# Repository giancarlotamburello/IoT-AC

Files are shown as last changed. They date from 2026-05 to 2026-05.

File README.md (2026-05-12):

<a href="https://www.ingv.it/" target="_blank" rel="noopener noreferrer">
<picture>
  <source media="(prefers-color-scheme: dark)" srcset="INGV_LOGO_STESO_SX_gray.svg">
  <source media="(prefers-color-scheme: light)" srcset="INGV_LOGO_STESO_SX.svg">
  
</picture>
</a>

<br></br>
<br></br>
<br></br>

# IoT-AC: Internet of Things - Accumulation Chamber Assembly Guide

This project provides the documentation and source files to build a low-cost, IoT-based accumulation chamber (**IoT-AC**) for measuring diffuse CO<sub>2</sub> fluxes.

## Overview

The **IoT-AC** is designed for environmental monitoring, with a focus on soil and volcanic degassing. The system leverages an ESP32 microcontroller to manage gas sensing and internal air homogenization, offering a portable, cost-effective alternative to professional scientific instrumentation. Performance was evaluated across two stages: controlled laboratory characterisation and field deployment within the active crater of Nea Kameni (Santorini). The resulting datasets are available [here](IOT_AC_DATA.md).

## Hardware Components

### Electronics

- **Microcontroller:** [ESP32](https://www.espressif.com/en/products/socs/esp32) (Dual-core, Wi-Fi/Bluetooth enabled).
- **CO2 Sensor:** [Sensirion SCD30](https://sensirion.com/products/catalog/SCD30) – A high-precision NDIR (Non-Dispersive Infrared) module.
- **Fan Motor:** Parallax Inc. bidirectional continuous rotation servomotor (0-50 RPM, 4.6 V).
- **Dupont jumper wires:** 10cm long Dupont jumper wires Female to Female and Male to Female.

### Chamber Specifications

We recommend using a **4-litre aluminium chamber** (e.g., a commercially available rice cooker pot) for the following reasons:

- **Dimensions:** ~20 cm internal diameter, 13 cm height.
- **Material:** Lightweight and durable.
- **Machining:** Easy to drill for mounting components.

> **Note:** Internal air homogenization is critical in closed-chamber systems to maintain a uniform concentration gradient. The integrated fan ensures this without disturbing the soil interface.

<figure>
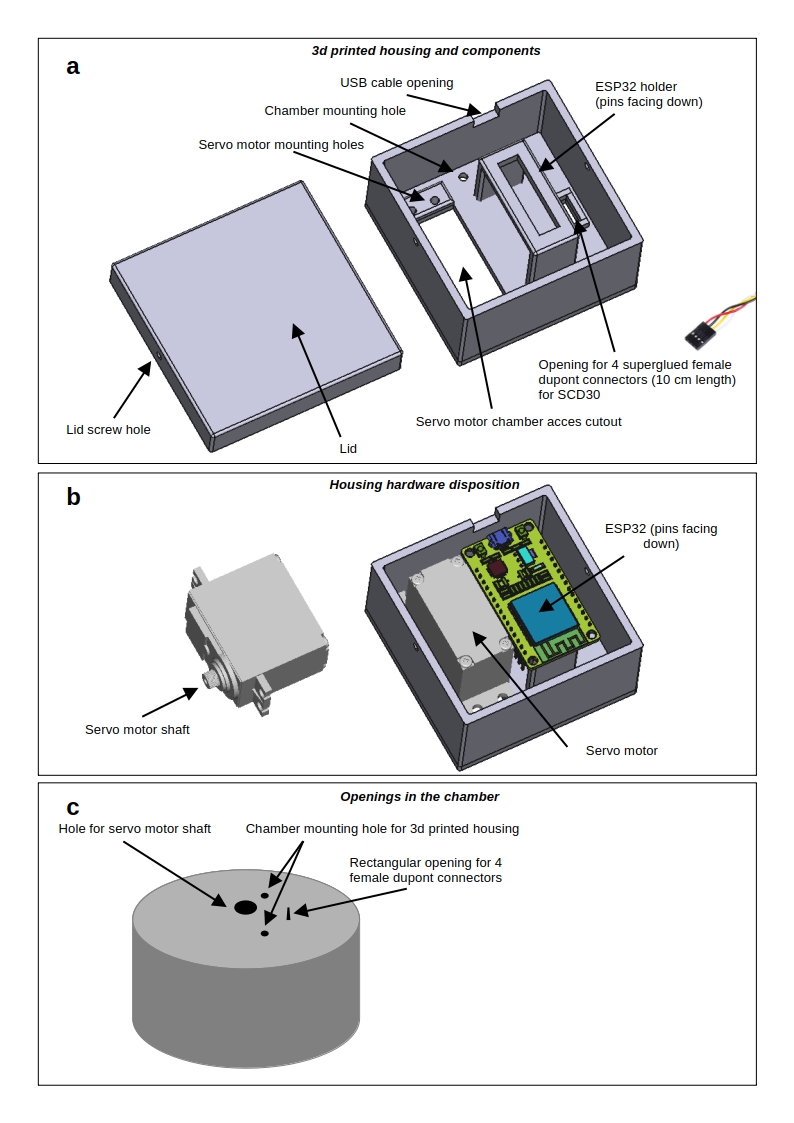
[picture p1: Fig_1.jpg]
  
  <figcaption>Figure 1: Description of the IoT-AC 3D-printed housing parts.</figcaption>
</figure>

---

## Assembly Guide

### 1. Preparation and Drilling

The file `iot_ac_case.3mf` serves as both the electronics enclosure and a **drilling template**. Align the housing on the chamber lid to mark and drill the following four holes (Fig. 1c-2a):

- **Servo Shaft Hole:** For the motor connection to the internal fan (must be at the centre of the chamber).
- **Fixation Holes (x2):** To secure the housing to the chamber body.
- **Sensor Port:** A small rectangular opening for the 4-pin female Dupont connectors used by the SCD30 sensor.

### 2. Mounting and Installation

- **Housing Attachment:** Once the holes are drilled, secure the 3D-printed housing to the chamber using two screws and bolts (Fig. 2b).
- **Servomotor:** Attach the servomotor to the housing using four self-tapping screws (Fig. 2c).
- **Sensor Interface:** Insert the four female Dupont connectors of the SCD30 into the rectangular hole and secure them with superglue (Fig. 2c-e).
  - _Benefit:_ This creates a modular port that allows the sensor to be connected easily inside the chamber and enables fast replacement in the field (Fig. 2d-f).

### 3. Wiring and Final Setup

- **Connections:** Wire the ESP32 to the servomotor and the SCD30 sensor according to the pinout diagram.
- **ESP32 Placement:** Place the ESP32 (pins facing down) onto its support within the housing, fixing it securely with double-sided tape (Fig. 2g).
- **Power:** Connect a USB cable to the ESP32. Ensure the cable length is sufficient for practical field operation.
- **Closure:** Close the housing lid and secure it with two self-tapping screws (Fig. 2h).

<figure>
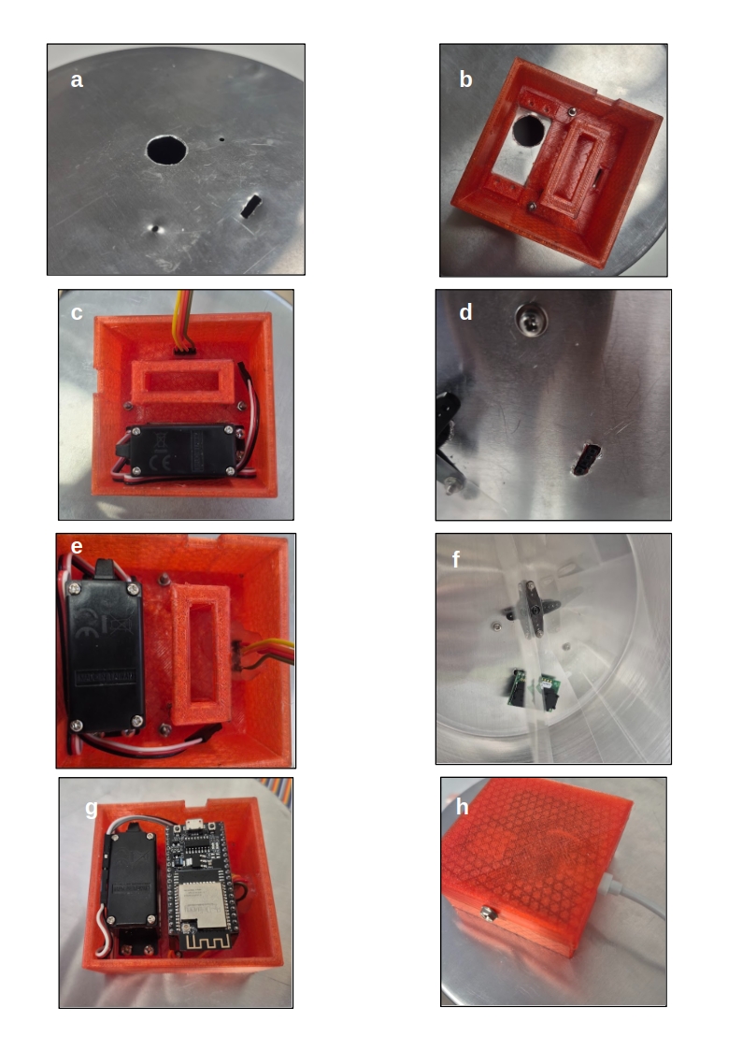
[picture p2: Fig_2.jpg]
  
  <figcaption>Figure 2: Photos of the steps for assembling the IoT-AC.</figcaption>
</figure>

---

## Install firmware and software

To get the system running, you will need to set up both the firmware in the ESP32 microcontroller and install the client application on an Android smartphone. Please refer to the specific documentation for each component:

### 🔌 Firmware

Flash the ESP32 microcontroller.

[**Buld & Flash docs →**](https://github.com/le0o0oo/d-flux/blob/main/firmware/README.md#build--flash)

### 📱 Client Application

Download the desktop/mobile app.

[**Releases →**](https://github.com/le0o0oo/d-flux/releases)

## License

This project is licensed under the **Creative Commons Attribution 4.0 International (CC BY 4.0)**. You are free to share and adapt this material, provided appropriate credit is given.

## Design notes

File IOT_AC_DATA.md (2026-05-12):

<a href="https://www.ingv.it/" target="_blank" rel="noopener noreferrer">
<picture>
  <source media="(prefers-color-scheme: dark)" srcset="https://github.com/giancarlotamburello/IoT-AC/blob/main/INGV_LOGO_STESO_SX_gray.svg">
  <source media="(prefers-color-scheme: light)" srcset="https://github.com/giancarlotamburello/IoT-AC/blob/main/INGV_LOGO_STESO_SX.svg">
  
</picture>
</a>

<br></br>
<br></br>
<br></br>

# IoT-AC: Internet of Things - Accumulation Chamber calibration and fieldwork data

Comprehensive results from laboratory evaluations and field deployments at the Nea Kameni volcano (Santorini) are provided at the bottom of this page, demonstrating the [IoT-AC](https://github.com/giancarlotamburello/IoT-AC/tree/main) system's full operational capacity.
The spreadsheet file contains three sheets (`Calibration_data`, `Calibration_raw_data`, `Nea_Kameni_data`):
* Sheet 1 (`Calibration_data`) contains calibration data, including simulated fluxes, the measured rate of CO<sub>2</sub> concentration change observed by the accumulation chamber, and the resulting recalculated measured fluxes.
* Sheet 2 (`Calibration_raw_data`) contains the raw CO<sub>2</sub> concentration time-series data for each individual measurement trial conducted during the calibration process.
* Sheet 3 (`Nea_Kameni_data`) contains diffuse flux data and geographic coordinates from fieldwork carried out at the Nea Kameni volcano in Santorini.

with the following fields:

* `Calibration_data`
  * CO<sub>2</sub> concentration	(% mol) - CO<sub>2</sub> concentration of gas standard used for simulating the diffuse flux
  * Flux reading 1 (mL·min<sup>-1</sup>) - Gas flux reading 1
  * Flux reading 2 (mL·min<sup>-1</sup>) - Gas flux reading 2
  * Flux reading 3 (mL·min<sup>-1</sup>) - Gas flux reading 3
  * Slope 1	(ppm·s<sup>-1</sup>) - Measurement 1 of CO<sub>2</sub> concentration rate
  * Slope 2	(ppm·s<sup>-1</sup>) - Measurement 2 of CO<sub>2</sub> concentration rate
  * Slope 3	(ppm·s<sup>-1</sup>) - Measurement 3 of CO<sub>2</sub> concentration rate
  * Slope 4	(ppm·s<sup>-1</sup>) - Measurement 4 of CO<sub>2</sub> concentration rate
  * Mean slope	(ppm·s<sup>-1</sup>) -	Average of the 4 measured CO<sub>2</sub> concentration rate
  * Diffuse flux	(g·m<sup>-2</sup>·d<sup>-1</sup>) -	Simulated diffuse flux calculated from concentration and average gas flux reading
  * Equation 1	(g·m<sup>-2</sup>·d<sup>-1</sup>) -	Recalculated diffuse flux using Equation 1
  * Equation 2	(g·m<sup>-2</sup>·d<sup>-1</sup>) -	Recalculated diffuse flux using Equation 2
* `Calibration_raw_data`
  * Timestamp	-	Timestamp in milliseconds inside the AC during measurement
  * Date - Timestring inside the AC during measurement
  * CO<sub>2</sub> (ppm) - CO<sub>2</sub> concentration inside the AC during measurement
  * Temperature (°C) -	Temperature inside the AC during measurement
  * Humidity (%) - Relative humidity inside the AC during measurement
* `Nea_Kameni_data`
  * time	-	Timestring at the beginning of the measurement
  * longitude	-	Longitude in decimal degree WGS84 of the measurement
  * latitude	-	Latitude in decimal degree WGS84 of the measurement
  * elevation	(m) -	Elevation above sea level of the measurement
  * WS CO<sub>2</sub> rate	(ppm·s<sup>-1</sup>) -	Measurement of CO<sub>2</sub> concentration rate of the West System AC
  * WS CO<sub>2</sub> flux	(g·m<sup>-2</sup>·d<sup>-1</sup>) -	Calculated CO<sub>2</sub> diffuse flux using equation 2 for the West System AC
  * IoT-AC CO<sub>2</sub> rate	(ppm·s<sup>-1</sup>) -	Measurement of CO<sub>2</sub> concentration rate of the IoT-AC
  * IoT-AC CO<sub>2</sub> flux	(g·m<sup>-2</sup>·d<sup>-1</sup>) -	Calculated CO<sub>2</sub> diffuse flux using equation 2 for the IoT-AC

---

### 📥 [Download Dataset (xlsx)](https://github.com/giancarlotamburello/IoT-AC/raw/refs/heads/main/iot_ac_calibration_fieldwork.xlsx)

---
### Data License
The data in this repository is licensed under a [Creative Commons Attribution 4.0 International License](https://creativecommons.org/licenses/by/4.0/).

**Please attribute this work as:**
> Tamburello G., Cardellini C., Rouwet D., Todesco M. (2026). A low-cost IoT-based accumulation chamber for measuring diffuse CO2 fluxes: calibration and field validation at Nea Kameni volcano (Santorini) [Dataset]. Istituto Nazionale di Geofisica e Vulcanologia (INGV). https://doi.org/10.13127/santorini/iot-accumchamb.1

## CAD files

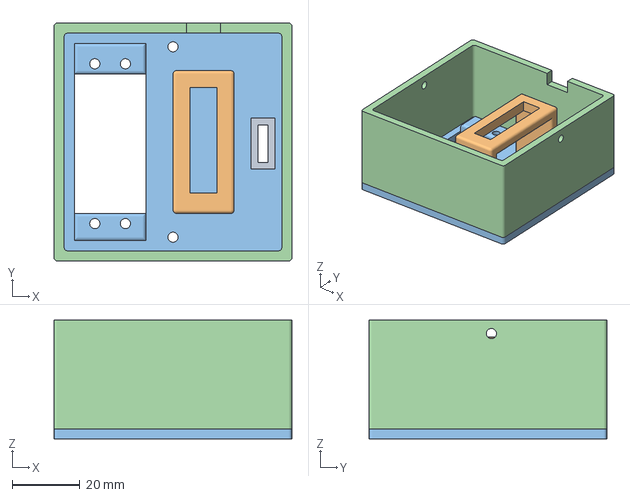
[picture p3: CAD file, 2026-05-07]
iot_ac_case.3mf
70.0 x 70.0 x 35.0 mm

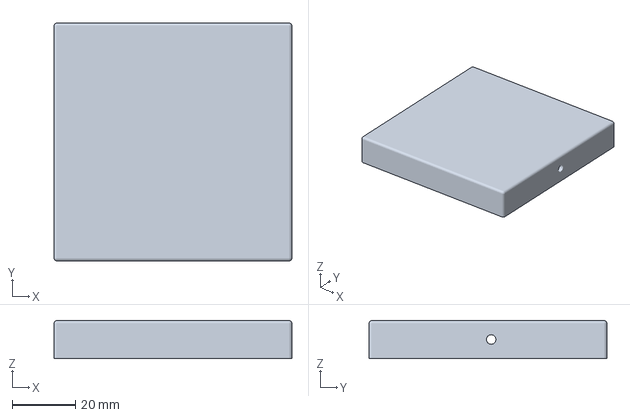
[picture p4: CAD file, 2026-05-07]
iot_ac_lid.3mf
75.0 x 75.0 x 12.0 mm

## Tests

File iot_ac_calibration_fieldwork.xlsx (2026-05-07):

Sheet: Calibration_data
IoT-AC |  |  |  |  |  |  |  |  |  | Recalculated flux
CO₂ concentration | Flux reading 1 | Flux reading 2 | Flux reading 3 | Slope 1 | Slope 2 | Slope 3 | Slope 4 | Mean slope | Diffuse flux | Equation 1 | Calibration | Calibration coefficients
% | mL·min⁻¹ |  |  | ppm·s⁻¹ |  |  |  | ppm·s⁻¹ | g·m⁻²·d⁻¹ | g·m⁻²·d⁻¹ |  | Slope (ppm·s⁻¹) | Intercept | R²
100.00% | 432.00 | 432.00 | 432.00 | 1412.0 | 1432.0 | 1463.0 | 1429.0 | 1434.0 | 38904.4891 | 29375.1 | 38307.6 | 26.71 | 0 | 0.9997
100.00% | 270.00 | 270.00 | 270.00 | 903.0 | 910.0 | 941.0 | 935.0 | 922.2 | 24315.30569 | 18892.0 | 24636.8
100.00% | 190.00 | 187.50 | 185.00 | 635.8 | 650.0 | 671.0 | 657.0 | 653.5 | 16885.62895 | 13385.7 | 17456.1 | P (Pa) | T (°C) | AC volume (m³) | AC height (m) | AC area (m²) | AC radius (m)
100.00% | 124.00 | 123.00 | 121.00 | 418.0 | 418.0 | 426.0 | 432.0 | 423.5 | 11046.95369 | 8675.3 | 11313.3 | 101000 | 20 | 0.004 | 0.13 | 0.0314 | 0.1
100.00% | 60.00 | 57.00 | 57.00 | 212.0 | 205.0 | 211.0 | 207.0 | 208.8 | 5223.287888 | 4276.2 | 5576.5
100.00% | 9.60 | 9.56 | 9.07 | 32.0 | 31.0 | 33.0 | 32.0 | 32.0 | 847.4334315 | 655.5 | 854.8
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

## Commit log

2026-05-08 Update figure caption for IoT-AC housing description
2026-05-11 Update README for IoT-AC assembly guide
